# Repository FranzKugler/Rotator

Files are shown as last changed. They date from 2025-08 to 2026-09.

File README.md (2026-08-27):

# Rotator

ESP32-S3 firmware for an astronomical instrument rotator. The device drives a
stepper motor, measures the shaft angle, exposes an **ASCOM Alpaca Rotator** over
the network, and serves a local browser interface for movement, calibration and
network setup.

The firmware is an ESP-IDF project with Arduino-ESP32 included as a component.
It targets a **Seeed Studio XIAO ESP32-S3 with 16 MB flash**.

## Features

- ASCOM Alpaca Rotator API and Alpaca discovery
- Absolute, relative and mechanical-angle movement
- TMC2209 stepper driver and FastAccelStepper motion control
- AS5600 magnetic angle feedback
- Hall-sensor mechanical-zero search
- Fourier-based angle-sensor calibration and an extended Kalman filter
- Browser UI from a LittleFS partition, including live angle updates
- Wi-Fi station support plus USB RNDIS networking
- USB CDC logging, FTP access and OTA firmware updates
- QlockThreeW32-style GitHub update channels (stable/edge), version checks,
  verified one-click installation, scheduled automatic updates and local image upload

## Hardware

| Function | Device / GPIO |
|---|---|
| Controller | Seeed Studio XIAO ESP32-S3, 16 MB flash |
| Stepper driver UART RX / TX | GPIO 7 / GPIO 8 |
| Stepper enable | GPIO 1 |
| Step / direction | GPIO 3 / GPIO 4 |
| AS5600 I²C SDA / SCL | GPIO 5 / GPIO 6 |
| AS5600 direction | GPIO 43 |
| Mechanical-zero Hall sensor | GPIO 2, active low with pull-up |

The current motion model assumes a 400-full-step motor, 256 microsteps and a
10:1 reduction. Hardware constants and the pin assignment live in
[`main/RotatorHW.cpp`](main/RotatorHW.cpp).

> **Warning:** the firmware moves to mechanical zero during startup. Do not run
> newly built firmware on connected mechanics until the pinout, travel and motor
> current have been checked.

## Development environment

The supported build environment is the repository's Docker/Dev Container. It
pins ESP-IDF 5.4.1 and Claude Code and keeps the ESP-IDF, npm and Claude state in
named volumes. Only this repository is bind-mounted into the container; no
Docker socket or host home directory is exposed.

Prerequisites on the host:

- Docker Engine with Docker Compose
- Git

```sh
# Build and start the development container
scripts/dev-container.sh up

# Test/build Svelte, then build firmware, bootloader, partitions and LittleFS
scripts/dev-container.sh build

# Only test and build the Svelte interface into main/data
scripts/dev-container.sh web

# Open an ESP-IDF shell
scripts/dev-container.sh shell

# Start Claude Code in the project
scripts/dev-container.sh claude
```

The first image build downloads ESP-IDF and installs the pinned Claude Code
release. The first project build resolves npm and ESP-IDF managed components.
The browser UI is a Svelte 5/Vite application under `web/`; its production
output replaces `main/data/` before ESP-IDF creates `littlefs.bin`.

### Releases and versions

The fallback project version starts at **0.8.0**. A release tag such as
`v0.8.0` produces the bare version `0.8.0`; later commits become strings such as
`0.8.0-4-gabc123`, matching QlockThreeW32. Pushes to `main` replace the rolling
`edge` pre-release, while `v*` tags create stable releases. Each release contains
`Rotator.bin`, `littlefs.bin` and a checksummed `manifest.json`.

### Direct ESP-IDF commands

Inside `scripts/dev-container.sh shell`:

```sh
idf.py set-target esp32s3
idf.py build
idf.py size
idf.py menuconfig
idf.py fullclean
```

The project defaults are in [`sdkconfig.defaults`](sdkconfig.defaults), and the
16 MB flash layout is in [`partitions.csv`](partitions.csv). Build artifacts are
written to `build/`; the generated LittleFS image is part of the normal
`idf.py build` because `main/CMakeLists.txt` calls
`littlefs_create_partition_image()`.

## Flashing and monitoring

USB devices are deliberately **not** passed into the normal development
container. This keeps ordinary builds and Claude Code isolated from host
hardware. Once a device is attached, identify its stable
`/dev/serial/by-id/...` path and add only that device in a local Compose
override before using:

```sh
idf.py -p /dev/serial/by-id/<device> flash monitor
```

Do not solve serial access with `privileged: true` or a blanket `/dev` mount.

## Project layout

```text
main/                       application firmware and generated browser UI
  alpaca_server/            ASCOM Alpaca API and discovery implementation
  data/                     files packed into the LittleFS image
components/                 vendored Arduino and hardware-related components
web/                        Svelte 5 source for the embedded interface
tests/                      web API unit tests
partitions.csv              16 MB flash layout
sdkconfig.defaults          ESP32-S3 project defaults
.devcontainer/              pinned Docker/Dev Container definition
scripts/dev-container.sh    host-side environment helper
```

Configuration is stored as `/lfs/config.json`. Wi-Fi credentials are stored in
NVS. The default USB RNDIS address is `192.168.7.1/24`; its locally administered
MAC address and the angle-correction coefficients are defined in
[`main/Configuration.cpp`](main/Configuration.cpp) and can be changed through
the web API.

## Current project status

This repository currently has no automated test suite. The minimum acceptance
check for every change is therefore a clean `idf.py build` in the pinned
container, followed by targeted hardware testing when motion, calibration,
networking, USB or flash behaviour is affected.

## License

No project-wide license file is currently present. Vendored components retain
their respective upstream licenses.

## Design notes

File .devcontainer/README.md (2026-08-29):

# Rotator development container

This environment pins ESP-IDF 5.4.1 by immutable image digest and Claude Code
2.1.247. Run it through `scripts/dev-container.sh` from anywhere inside the
repository.

State is separated as follows:

- repository: bind-mounted at `/workspace`;
- compiler cache: named `idf-cache` volume;
- npm cache: named `npm-cache` volume;
- Claude Code account and sessions: named `claude-state` volume;
- SSH keys and known_hosts: named `ssh-state` volume, mounted at
  `/home/developer/.ssh`.

The service runs as a non-root user matching Franz's host UID/GID. It has all
Linux capabilities dropped, `no-new-privileges`, no Docker socket, no host-home
mount, no published ports and no hardware devices.

Authenticate Claude independently inside the container with
`scripts/dev-container.sh claude`. Credentials stay in the private named volume
and are neither baked into the image nor committed to Git.

USB flashing is intentionally separate. Add only a stable
`/dev/serial/by-id/...` device in a local Compose override after the target is
attached; never enable privileged mode or mount all of `/dev`.

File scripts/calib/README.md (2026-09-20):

# Rotator calibration campaign

A from-scratch calibration of the rotator's angle chain, built 2026-09-18.
Everything here drives real hardware over the network; nothing is simulated
except where a script says so.

    rotator   172.22.102.30      expert mode must be unlocked
    camera    172.22.102.226     RotatorCam, GET /capture

## The chain, and where each part is measured

    stepper --- AS5600 --- 10:1 reduction --- output shaft --- chessboard
                  |                                               |
            sensor sees this                             camera sees this

The AS5600 sits on the motor shaft, so it measures the motor and only
*infers* the output. That split decides the whole campaign: everything
upstream of the reduction can be calibrated from the sensor alone, and
everything downstream cannot be seen by it at all.

## Order of operations

| Step | Script | What it establishes |
|---|---|---|
| 1 | `sweep_fullstep.py` | raw sensor at each of the 400 full steps, forward and reverse. The firmware now does the same thing itself - `GET /api/calibration/angle/stream` - so this is the research version, not the only way |
| 2 | `fit_sensor.py` | Fourier correction, order chosen from the data; hysteresis and repeatability |
| 3 | `plot_sensor.py` | the calibration graphs |
| 4 | `upload_coefficients.py` | writes the fit to the device without moving its zero |
| 5 | `capture_frames.py --mode steps` | camera frames at exactly known positions |
| 6 | `fit_camera.py` | camera geometry (see the caveat below) |
| 7 | `gear_error.py` + `plot_gear.py` | what the sensor cannot see |
| 8 | `control_lab.py` | P / PI / PD / PID compared on the real machine |
| 8b | `log_tail.py` | drains the device's /log ring buffer, which wraps in ~30 s |
| 9 | `capture_frames.py --mode alpaca` + `measure_frames.py` | the end-to-end test run |
| 10 | `error_budget.py` | splits that run into loop / backlash / gear shape, cross-validated |
| 10b | `angle_service.py` | serves the output-shaft angle over HTTP, so the device can calibrate against it by itself |
| 11 | `plot_validation.py` | the test-run graph |

`rotator_io.py`, `board.py`, `camera_model.py`, `gear_model.py` and
`vizstyle.py` are the shared layers; none of them is a program.

`capture_frames.py --mode alpaca` takes two options that exist because of
what step 10 found: `--approach-deg` reaches every target from the same
side, which removes the gear backlash the firmware's loop cannot see, and
`--precompensate` shifts each target by a measured gear model so the shaft
lands where the target says rather than where the sensor says.

## Three things that will bite

**OpenCV's solver path crashes here.** This machine's CPU is a QEMU virtual
CPU with SSE4.2 and no AVX, and OpenCV's Levenberg-Marquardt code hits an
illegal instruction on it. `cv2.calibrateCamera`, `cv2.findHomography`,
`cv2.solvePnP` with `SOLVEPNP_ITERATIVE` and `cv2.solvePnPRefineLM` all die
with SIGILL - no exception, no traceback, just a dead process. The
closed-form routines are fine: `findChessboardCornersSB`, `solvePnP` with
`SOLVEPNP_IPPE`, `undistortPoints`, `projectPoints`, `Rodrigues`.
`camera_model.py` therefore carries its own DLT homography and its own
least-squares fits.

**The board's orientation is ambiguous by 180 degrees.** The 8x7 interior-
corner grid maps onto itself under a half turn, so both pairings fit
perfectly and no geometric test can separate them. `board.py` explains it;
`measure_frames.resolve_flips()` settles it against the rotator's own
reported position.

**Focal length is not observable on this rig.** The board plane sits within
0.1 degrees of perpendicular to the rotation axis, so rotating it produces
no new plane orientations and the focal length is free. A first fit ran away
to f = 8000 px while still reproducing corners to 0.29 px. This is not a
problem to solve - a board that stays in one fixed plane is the easy case,
and the homography-ratio estimator in `measure_frames.py` never needs a
focal length. `fit_camera.py` is kept for the diagnosis, not for production.

## Letting the device calibrate itself against the camera

The firmware can run the output-angle calibration on its own - a button in
the web UI, `GET /api/calibration/camera/stream` underneath - but it does no
image processing. It asks an HTTP address for a number. `angle_service.py`
is what answers, until RotatorCam serves angles itself:

    python3 scripts/calib/angle_service.py --camera 172.22.102.226 --port 8080

Then set the device's angle source (web UI, or POST
`/api/calibration/camera-source`) to `http://<that host>:8080/angle` and
press the button.

**It has to be reachable from the rotator, which the dev container is not.**
The container sits on a Docker bridge (172.23.0.0/16) that the rotator's
network does not route to, and `compose.yaml` publishes only the Vite port,
bound to localhost. Run the service on the host instead - it needs numpy and
opencv, the same throwaway venv as the rest of the analysis - or publish a
port from the container deliberately.

If the sign comes out inverted the device will refuse the result rather than
store it: a correction that big cannot be a gear error, and it says so.
Re-run the service with `--invert`.

## Environments

Acquisition is standard library only and runs under the container's own
python3. Analysis needs numpy, scipy, opencv and matplotlib in a throwaway
venv, per the note in `../requirements-camera-analysis.txt`:

    python3 -m venv /tmp/cv4
    /tmp/cv4/bin/pip install "opencv-python-headless==4.10.0.84" numpy scipy matplotlib

## Results as of 2026-09-18

Measured on the one unit, after the firmware switched to the AS5600's RAW
ANGLE register:

| | |
|---|---|
| sensor characteristic, uncorrected | 0.225 deg p-p |
| after the order-5 Fourier fit | 3.0 mdeg rms |
| useful harmonic orders | 1..5; order 6 and beyond are 0.02-0.03 counts, i.e. noise |
| forward repeatability | 1.3 mdeg |
| direction hysteresis (motor shaft) | 27.9 mdeg |
| camera repeatability | 2.3 mdeg (1.3 mdeg over 3 frames) |
| **output error the sensor cannot see** | **~37 mdeg rms, ~150 mdeg p-p** |
| direction split on randomly ordered targets | 64 mdeg p-p, 38.7 after the firmware's one-sided approach |
| lost motion on reversal | ~89 mdeg |
| position hysteresis no approach length removes | ~25-30 mdeg |
| firmware closed loop, sensor against Alpaca target | 3.9 mdeg rms |

The last two lines matter together: the firmware already positions the motor
shaft to better than 0.01 degrees, so every remaining error is downstream of
the reduction. Approaching every target from the same side removes the part of the split
that is backlash; `refineToTarget()` and `holdTask()` now do that on their
own, and `--approach-deg` does the same from the host side. What is left is
stiction, which no approach discipline touches.

The gear error is the accuracy floor of a calibration done without a camera.
It reproduced across two runs taken at different step spacings, agreeing to
0.8 degrees of phase on its dominant term, so it is a fixed property of the
machine and correctable - but only against an external reference.

The device stores orders up to KMAX = 5 as of v0.10.0, with the NVS blob
carrying its own KMAX and migrating a smaller one. Coefficients, mechanical
zero and full-step table share a generation number so a correction replaced
without re-measuring the other two is reported rather than silently applied -
`GET /api/calibration/status`, and `upload_coefficients.py --keep-zero` for
the one case where the caller has arranged for the zero to stay valid.

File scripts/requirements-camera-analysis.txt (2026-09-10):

# Only scripts/camera_angle_analyze.py needs these - deliberately NOT part of
# the ESP-IDF dev container's pinned Python env (see CLAUDE.md: don't install
# extra Python packages on the toolchain host). Use a throwaway venv:
#
#   python3 -m venv /tmp/camvenv
#   /tmp/camvenv/bin/pip install -r scripts/requirements-camera-analysis.txt
#   /tmp/camvenv/bin/python scripts/camera_angle_analyze.py --sweep-dir ...
numpy
opencv-python-headless

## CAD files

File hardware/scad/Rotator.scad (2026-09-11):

include <BOSL2/std.scad>
include <BOSL2/ball_bearings.scad>
include <BOSL2/screws.scad>

$fn=256;
extension_tube_outer_diameter = 44.5;
extension_tube_inner_diameter = 42;
bearing_outer_diameter = 72.4;
bearing_inner_diameter = 55.2;
bearing_height = 9;
no_of_clips = 3;
motor_distance = 75.8;  // calculated optimal distance of motor in x direction dependent on the used beltlength
cover_length = 50;      // length of motor cover - 20, so this is 70 long in fact
cover_width = 26;       // width of motor cover - 20, so this is 46 wide in fact
with_supports = true;
with_bearing_clips = false;


module esp_clip(){
    difference() {
        hull(){
            translate([0,-10.5,0])cylinder(d=4, h=2);
            translate([0, 10.5,0])cylinder(d=4, h=2);
        }
        translate([0,-10.5,-1])cylinder(d=2.5, h=4);
        translate([0, 10.5,-1])cylinder(d=2.5, h=4);
    }
}

module tmc_clip(){
    difference(){
        union(){
            hull(){
                translate([0,-9,0])cylinder(d=4, h=2);
                translate([0, 9,0])cylinder(d=4, h=2);
            }    
            hull(){
                translate([-2,-2,0])cylinder(d=4, h=2);
                translate([-2, 2,0])cylinder(d=4, h=2);
            }  
        }
        translate([0,-9,-1])cylinder(d=2.5, h=4);
        translate([0, 9,-1])cylinder(d=2.5, h=4);
    }
}

module sensor_clip(){
    difference(){
        cuboid([4,8,2], anchor=BOTTOM);
        translate([0,0,-1])cylinder(d=2.5, h=4);
    }
    translate([2,0,0])cuboid([2,8,6], anchor=BOTTOM+LEFT);
}

module hall_clip() {
    difference() {
        diff() prismoid([7,10-0.8],[7,5.65-0.8], height=2.6, anchor=BOTTOM+LEFT) edge_profile(TOP+RIGHT, excess=2)mask2d_roundover(h=1); 
        translate([1.6,0,-1])cuboid([3.4,4.5,3], anchor=BOTTOM+LEFT);
        translate([-1,0,-1])cuboid([4,3.6,2], anchor=BOTTOM+LEFT);
    }   
}

module distance_ring(h=5) {
    difference(){
        union(){
            // tube with outer diameter and thread with inner diameter
            cylinder(d=extension_tube_outer_diameter, h=h);
            translate([0,0,h]) threaded_rod(d=extension_tube_inner_diameter, pitch=0.75, h=6);
        }
        // minus the bore of the tube itself
        translate([0,0,-1])cylinder(d=extension_tube_inner_diameter-2, h=h+4);
    }
}
  
module rotating_ring(){
    difference(){
        // pulley with dome
        union(){
            import("Imports/BigPulley.obj");
            translate([0,0,5.2+2.2])cyl(h=5, d1=94, d2=94-6, rounding1=-2, rounding2=2);
           
        }
        // hole for the extension tube
        translate([0,0,-1])cyl(d=extension_tube_outer_diameter+0.2, h=10.9, chamfer2=-0.6, anchor=BOTTOM);
        // carve out inner part
        translate([0,0,8.6/2])cyl(h=8.6, d=bearing_outer_diameter+13, rounding1=-1, rounding2=1);
        // hole for the index magnet
        translate([-(bearing_outer_diameter+13)/2-3.6,0,4.1])yrot(90)cyl(d=6.3, h=4, chamfer1=-0.4, anchor=BOTTOM);

        
    }
    // inner cylinder connected to inner ring of the bearing
    difference(){
        // cylinder
        translate([0,0,-1])cylinder(d=bearing_inner_diameter, h=9.7);
        // minus the hole for the extension tube
        translate([0,0,-1])cylinder(d=extension_tube_outer_diameter+0.2, h=12); 
        // minus the 45deg phase
        //translate([0,0,0])cylinder(h=(bearing_inner_diameter-extension_tube_outer_diameter)/2, d1=bearing_inner_diameter, d2=extension_tube_outer_diameter);
        translate([0,0,-1.4])cyl(d=bearing_inner_diameter-2, h=6.5, rounding2=(bearing_inner_diameter-extension_tube_outer_diameter)/2, anchor=BOTTOM);
        // trim to height
        translate([0,0,-1])cylinder(h=1, d=55);
        // cutouts for bearing clips
        if(with_bearing_clips)  
            for (w=[0:360/no_of_clips:360-360/no_of_clips])rotate([0,0,w])translate([-bearing_inner_diameter/2-2,-3.5, -2]) cube([4,7,11]);
    }
    // bearing seat
    difference(){
        translate([0,0,7.6+0.2])cylinder(d=bearing_inner_diameter+5, h=1.2);
        translate([0,0,6])cylinder(d=bearing_inner_diameter-5, h=5);
    }
    // tube stop ring
    difference() {
        union(){
            #translate([0,0,5.0])cylinder(d1=extension_tube_outer_diameter+2,d2=extension_tube_outer_diameter-3, h=1.4);
            translate([0,0,5.0+4.7/2])threaded_rod(d=extension_tube_inner_diameter+0.2, pitch=0.75, h=4.7);
            translate([0,0,9.5])cylinder(d=extension_tube_inner_diameter-1, h=0.2);
            }
        translate([0,0,2.0])cylinder(d=extension_tube_inner_diameter-2.4, h=10);
    }

    // bearing clips
    if(with_bearing_clips){
        for (w=[0:360/no_of_clips:360-360/no_of_clips])rotate([0,0,180 + w + 180 * 5 / bearing_outer_diameter / PI])
        difference(){
            translate([0,0,-1.6])cyl(d=bearing_inner_diameter, h=9.4, rounding1=-1, anchor=BOTTOM);
            translate([0,0,-2])pie_slice(h = 12, d=bearing_inner_diameter+3, ang = 360-360 * 5 / bearing_outer_diameter / PI, anchor=BOTTOM);
            translate([0,0,-3])cyl(h=10.5, d1=bearing_inner_diameter-2, d2=bearing_inner_diameter-2, rounding2=1, anchor=BOTTOM);
            translate([0,0,-3])cylinder(h=13, d=bearing_inner_diameter-6);
        }
    }
    // eventually print support ring
    if (with_supports) translate([0,0,9.9-1.4])difference(){
        cyl(d=105, h=1.4, anchor=BOTTOM);
        translate([0,0,-0.1])cylinder(d=91, h=2);
    } 
    if (false) translate([0,0,9.9-1.6])difference(){
        cyl(d=extension_tube_inner_diameter, h=1.6, anchor=BOTTOM);
        translate([0,0,-0.1])cylinder(d=extension_tube_inner_diameter-8, h=2);
        }
}  

module small_pulley(){
    difference(){
        import("Imports/SmallPulley.obj");
        translate([0,0,-1])cyl(d=5.3, h=9.2, chamfer2=-1, anchor=BOTTOM, $fn=64);
        // magnet
        translate([0,0,-1])cylinder(d=6.3, h=3.1,   $fn=64);
        // room for sensor
        translate([0,0,-1])cylinder(d=8,   h=1.8, $fn=64);
    }
    // add index D-Shape
    rotate([0,0,-90])translate([2.1,-2.5,2.5]) cube([0.7,5,4]);  
}

module mounting_post(){
    difference(){
        translate([0,0,6.2])cyl(d=8, h=12.4, rounding1=-2); 
        translate([0,0,3.5+12.4-7])cyl(d=4, h=7, chamfer2=-0.4);
        translate([0,0,2])cylinder(d=3.3, h=12);
    }   
}

// bottom housing
module bottom (){
    difference(){
        // bottom plate
        union(){
            hull(){
                translate([0,0,-1])cyl(d=140, h=2, chamfer1=1);
                translate([-90,-60,-1])cyl(d=20, h=2, chamfer1=1);
                translate([-90, 60,-1])cyl(d=20, h=2, chamfer1=1);
                
            }
            // tube foot
            cylinder(h=5, d1=49, d2=45);
            // tube main cylinder where the thread gets cut out
            translate([0,0,2])cyl(h=4, d=47, rounding2=1, anchor=BOTTOM);
        }
        // hole for extension tube
        translate([0,0,-2])cyl(d=extension_tube_outer_diameter, h=6, chamfer1=-1, anchor=BOTTOM);
        // thread for extension tube
        translate([0,0,3])threaded_rod(d=extension_tube_inner_diameter+0.6, pitch=0.75, h=6);
        // pocket for rotation sensor
        translate([-motor_distance,0,-1.4])cuboid([23.6,23.8,2], rounding=3.2, edges=[FWD+RIGHT,FWD+LEFT,BACK+RIGHT,BACK+LEFT], anchor=BOTTOM); //rounding=3.5
        // cutout for hall sensor
        translate([-bearing_outer_diameter/2-2,0,-1])cuboid([20,5.65,2], chamfer=-1, edges=[BOTTOM+FRONT,BOTTOM+BACK], anchor=BOTTOM+RIGHT);
        translate([-bearing_outer_diameter/2-6,0,-1])rotate([0,-90,0])prismoid([11,10],[11,4], height=4, anchor=TOP+LEFT);
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

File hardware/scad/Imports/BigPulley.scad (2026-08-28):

// Parametric Pulley with multiple belt profiles
// by droftarts January 2012
// updated and changed by Oscar January 2018 (https://www.thingiverse.com/0scar/about)

// Based on pulleys by:
// http://www.thingiverse.com/thing:11256 by me!
// https://github.com/prusajr/PrusaMendel by Josef Prusa
// http://www.thingiverse.com/thing:3104 by GilesBathgate
// http://www.thingiverse.com/thing:2079 by nophead

// dxf tooth data from http://oem.cadregister.com/asp/PPOW_Entry.asp?company=915217&elementID=07807803/METRIC/URETH/WV0025/F
// pulley diameter checked and modelled from data at http://www.sdp-si.com/D265/HTML/D265T016.html

/**
 * @name Pulley
 * @category Printed
 * @using 1 x m3 nut, normal or nyloc
 * @using 1 x m3x10 set screw or 1 x m3x8 grub screw
 */

// ------------------------
// Idler profile parameters
// ------------------------
number_of_teeth = 160; // [10:100]
profile = 12; // [1:MXL, 2:40DP, 3:XL, 4:H, 5:T2.5, 6:T5, 7:T10, 8:AT5, 9:HTD_3mm, 10:HTD_5mm, 11:HTD_8mm, 12:GT2_2mm, 13:GT2_3mm, 14:GT2_5mm]
motor_shaft_diameter = 8.2; // (in mm)
toothed_part_length = 6.2; // [3:30] (in mm)
base_height = 0; // [0:30] (in mm, 6 is typical)
base_diameter = 20;   // [10:50] (in mm)

// ---------------------------
// Idler & retainer parameters
// ---------------------------
belt_retainer = 1; // [0:No, 1:Yes]
retainer_height_p = 1.0; // [0.5:Tiny (0.5mm), 1:Small (1mm), 1.5:Normal (1.5mm), 2:Big (2mm), 3:Bigger (3mm), 4:Hudge (5mm)]
belt_idler = 1; // [0:No, 1:Yes]
// Height of idler flange over pulley. Set to same as base height if you want an idler but no pulley.
idler_height_p = 1.0; // [0.5:Tiny (0.5mm), 1:Small (1mm), 1.5:Normal (1.5mm), 2:Big (2mm), 3:Bigger (3mm), 4:Hudge (5mm)]

// ---------------
// Shaft fastening
// ---------------
screws_disposition = 3; // [0:None, 1:1 screw, 2:2 screws at 90deg, 3:3 screws at 120deg, 4:4 screws at 90deg]
nut_shape = 1; // [1:Hexagonal, 0:Square]
screw_profile = 4; // [0:M1, 1:M1.6, 2:M2, 3:M2.5, 4:M3, 5:M4, 6:M5, 7:M6]

// Distance between inner face of nut and shaft - can be negative - (in mm).
nut_shaft_distance = 1.2;

// Bolt head shape (0 is inactive) subtracts a bolt head sized hexagon for hexagon bolts
idler_bolt_option = 0; // [0:none, 1:M3, 2:M4, 3:M5, 4:M6, 5:M8, 6:M10, 7:M12, 8:custom] for custom: make changes below!

// Optional metal flange attachment (0 is inactive)
flange_option = 1;
flange_screw_profile = 5; // [0:M1, 1:M1.6, 2:M2, 3:M2.5, 4:M3, 5:M4, 6:M5, 7:M6]
flange_screws_disposition = 4; // [0:None, 1:1 screw, 2:2 screws at 180deg, 3:3 screws at 120deg, 4:4 screws at 90deg]
flange_screwoffset_radius = 26/2;
flange_diam = 32; // Set to zero to disable the flange to be sunk in the idler
flange_thickness = 3; // Set to zero to disable the flange to be sunk in the idler
flange_use_tap = 1; // Diameter is smaller when used for tapping, 0 to larger hole for easy fit


// --------------------------------------------------
// ADVANCED parameters for scaling tooth for good fit
// --------------------------------------------------
// To improve fit of belt to pulley, set the following constant.
// Decrease or increase by 0.1mm at a time. We are modelling the
// *BELT* tooth here, not the tooth on the pulley. Increasing the
// number will *decrease* the pulley tooth size. Increasing the
// tooth width will also scale proportionately the tooth depth,
// to maintain the shape of the tooth, and increase how far into
// the pulley the tooth is indented. Can be negative too!
additional_tooth_width = 0.2; //mm
// If you need more tooth depth than this provides, adjust the
// following constant. However, this will cause the shape of the
// tooth to change.
additional_tooth_depth = 0; //mm

// ------------------------------------
// Calculated parameters (do not alter)
// ------------------------------------
idler_height = (belt_idler==0 ? 0 : idler_height_p);
retainer_height = (belt_retainer==0 ? 0 : retainer_height_p);
//echo (str("Idler height\t= ",idler_height," mm"));
//echo (str("Retainer height\t= ",retainer_height," mm"));
no_of_nuts = screws_disposition;
nut_angle = no_of_nuts != 3 ? 90 : 120;
motor_shaft = motor_shaft_diameter + 0.2;
screw_diameters = [1, 1.6, 2, 2.5, 3, 4, 5, 6];
nut_widths = [2.5, 3.2, 4, 5, 5.5, 7, 8, 10];
nut_depths = [1, 1.3, 1.6, 2, 2.4, 3.2, 4.7, 5.2];
// bolthead size circ.[ none,    M3,    M4,   M5,    M6,    M8,   M10,   M12, custom]
bolt_head_diameters = [0.000, 6.010, 7.660, 8.79, 11.05, 14.38, 17.77, 20.03,  15.8]; // circle diameter, not width across flats!
bolt_head_heights =   [0.000, 2.125, 2.925, 3.65,  4.15,  5.45,  6.58,  7.68,   5.5];
screw_diameter = screw_diameters[screw_profile] + 0.2;
nut_width = nut_widths[screw_profile] + 0.2;
nut_depth = nut_depths[screw_profile] + 0.3;
bolt_head_diam = bolt_head_diameters[idler_bolt_option] + 0.2; // + 0.1-2 for tight fit
bolt_head_height = bolt_head_heights[idler_bolt_option] + 0.2;
screw_hole_sf = flange_use_tap == 1 ? 0.9 : 1.1; // 0.9 is the recommended value for taps of fine thread, 0.85 for coarse threads
flange_screw_diameter = screw_diameters[flange_screw_profile] * screw_hole_sf; 
flange_no_of_screws = flange_screws_disposition;
flange_screw_angle = flange_no_of_screws != 3 ? (flange_no_of_screws == 2 ? 180 : 90) : 120;

// --------------------
// Calculated constants
// --------------------
nut_elevation = base_height/2;
metric_nut_width_across_points = 2*((nut_width/2)/cos(30)); // This is needed for the nut trap
// The following set the pulley diameter for a given number of teeth
MXL_pulley_dia = tooth_spacing (2.032,0.254);
40DP_pulley_dia = tooth_spacing (2.07264,0.1778);
XL_pulley_dia = tooth_spacing (5.08,0.254);
H_pulley_dia = tooth_spacing (9.525,0.381);
T2_5_pulley_dia = tooth_spaceing_curvefit (0.7467,0.796,1.026);
T5_pulley_dia = tooth_spaceing_curvefit (0.6523,1.591,1.064);
T10_pulley_dia = tooth_spacing (10,0.93);
AT5_pulley_dia = tooth_spaceing_curvefit (0.6523,1.591,1.064);
HTD_3mm_pulley_dia = tooth_spacing (3,0.381);
HTD_5mm_pulley_dia = tooth_spacing (5,0.5715);
HTD_8mm_pulley_dia = tooth_spacing (8,0.6858);
GT2_2mm_pulley_dia = tooth_spacing (2,0.254);
GT2_3mm_pulley_dia = tooth_spacing (3,0.381);
GT2_5mm_pulley_dia = tooth_spacing (5,0.5715);
// The following calls the pulley creation part, and passes the pulley diameter and tooth width to that module
if ( profile == 1 ) {pulley("MXL" , MXL_pulley_dia , 0.508 , 1.321 ); }
if ( profile == 2 ) {pulley("40 D.P." , 40DP_pulley_dia , 0.457 , 1.226 ); }
if ( profile == 3 ) {pulley("XL" , XL_pulley_dia , 1.27, 3.051 ); }
if ( profile == 4 ) {pulley("H" , H_pulley_dia ,1.905 , 5.359 ); }
if ( profile == 5 ) {pulley("T2.5" , T2_5_pulley_dia , 0.7 , 1.678 ); }
if ( profile == 6 ) {pulley("T5" , T5_pulley_dia , 1.19 , 3.264 ); }
if ( profile == 7 ) {pulley("T10" , T10_pulley_dia , 2.5 , 6.13 ); }
if ( profile == 8 ) {pulley("AT5" , AT5_pulley_dia , 1.19 , 4.268 ); }
if ( profile == 9 ) {pulley("HTD 3mm" , HTD_3mm_pulley_dia , 1.289 , 2.27 ); }
if ( profile == 10 ){pulley("HTD 5mm" , HTD_5mm_pulley_dia , 2.199 , 3.781 ); }
if ( profile == 11 ){pulley("HTD 8mm" , HTD_8mm_pulley_dia , 3.607 , 6.603 ); }
if ( profile == 12 ){pulley("GT2 2mm" , GT2_2mm_pulley_dia , 0.764 , 1.494 ); }
if ( profile == 13 ){pulley("GT2 3mm" , GT2_3mm_pulley_dia , 1.169 , 2.31 ); }
if ( profile == 14 ){pulley("GT2 5mm" , GT2_5mm_pulley_dia , 1.969 , 3.952 ); }

// ---------
// Functions
// ---------
function tooth_spaceing_curvefit (b,c,d)
  = ((c * pow(number_of_teeth,d)) / (b + pow(number_of_teeth,d))) * number_of_teeth ;

function tooth_spacing(tooth_pitch,pitch_line_offset)
  = (2*((number_of_teeth*tooth_pitch)/(3.14159265*2)-pitch_line_offset)) ;

// ================================================================================
// Main Module
// ================================================================================
module pulley( belt_type , pulley_OD , tooth_depth , tooth_width ){
  echo (str("Belt type = ",belt_type,"; Number of teeth = ",number_of_teeth,"; Pulley Outside Diameter = ",pulley_OD,"mm "));
  tooth_distance_from_centre = sqrt( pow(pulley_OD/2,2) - pow((tooth_width+additional_tooth_width)/2,2));
  tooth_width_scale = (tooth_width + additional_tooth_width ) / tooth_width;
  tooth_depth_scale = ((tooth_depth + additional_tooth_depth ) / tooth_depth) ;

  difference(){   
    translate([0,0,idler_height]){
      union(){
        //base
        if (( base_height < 2 ) && (no_of_nuts > 0)){ 
          if (base_height != 0){
            echo ("CAN'T DRAW PULLEY BASE, HEIGHT LESS THAN 2!!!"); 
          }
        } else {
          translate([0,0,-idler_height]){
            cylinder(d=base_diameter, h=base_height, $fn=base_diameter*20, center=false);
          }
        }
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

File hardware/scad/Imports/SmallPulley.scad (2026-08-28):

// Parametric Pulley with multiple belt profiles
// by droftarts January 2012
// updated and changed by Oscar January 2018 (https://www.thingiverse.com/0scar/about)

// Based on pulleys by:
// http://www.thingiverse.com/thing:11256 by me!
// https://github.com/prusajr/PrusaMendel by Josef Prusa
// http://www.thingiverse.com/thing:3104 by GilesBathgate
// http://www.thingiverse.com/thing:2079 by nophead

// dxf tooth data from http://oem.cadregister.com/asp/PPOW_Entry.asp?company=915217&elementID=07807803/METRIC/URETH/WV0025/F
// pulley diameter checked and modelled from data at http://www.sdp-si.com/D265/HTML/D265T016.html

/**
 * @name Pulley
 * @category Printed
 * @using 1 x m3 nut, normal or nyloc
 * @using 1 x m3x10 set screw or 1 x m3x8 grub screw
 */

// ------------------------
// Idler profile parameters
// ------------------------
number_of_teeth = 160; // [10:100]
profile = 12; // [1:MXL, 2:40DP, 3:XL, 4:H, 5:T2.5, 6:T5, 7:T10, 8:AT5, 9:HTD_3mm, 10:HTD_5mm, 11:HTD_8mm, 12:GT2_2mm, 13:GT2_3mm, 14:GT2_5mm]
motor_shaft_diameter = 8.2; // (in mm)
toothed_part_length = 6.2; // [3:30] (in mm)
base_height = 0; // [0:30] (in mm, 6 is typical)
base_diameter = 20;   // [10:50] (in mm)

// ---------------------------
// Idler & retainer parameters
// ---------------------------
belt_retainer = 1; // [0:No, 1:Yes]
retainer_height_p = 1.0; // [0.5:Tiny (0.5mm), 1:Small (1mm), 1.5:Normal (1.5mm), 2:Big (2mm), 3:Bigger (3mm), 4:Hudge (5mm)]
belt_idler = 1; // [0:No, 1:Yes]
// Height of idler flange over pulley. Set to same as base height if you want an idler but no pulley.
idler_height_p = 1.0; // [0.5:Tiny (0.5mm), 1:Small (1mm), 1.5:Normal (1.5mm), 2:Big (2mm), 3:Bigger (3mm), 4:Hudge (5mm)]

// ---------------
// Shaft fastening
// ---------------
screws_disposition = 3; // [0:None, 1:1 screw, 2:2 screws at 90deg, 3:3 screws at 120deg, 4:4 screws at 90deg]
nut_shape = 1; // [1:Hexagonal, 0:Square]
screw_profile = 4; // [0:M1, 1:M1.6, 2:M2, 3:M2.5, 4:M3, 5:M4, 6:M5, 7:M6]

// Distance between inner face of nut and shaft - can be negative - (in mm).
nut_shaft_distance = 1.2;

// Bolt head shape (0 is inactive) subtracts a bolt head sized hexagon for hexagon bolts
idler_bolt_option = 0; // [0:none, 1:M3, 2:M4, 3:M5, 4:M6, 5:M8, 6:M10, 7:M12, 8:custom] for custom: make changes below!

// Optional metal flange attachment (0 is inactive)
flange_option = 1;
flange_screw_profile = 5; // [0:M1, 1:M1.6, 2:M2, 3:M2.5, 4:M3, 5:M4, 6:M5, 7:M6]
flange_screws_disposition = 4; // [0:None, 1:1 screw, 2:2 screws at 180deg, 3:3 screws at 120deg, 4:4 screws at 90deg]
flange_screwoffset_radius = 26/2;
flange_diam = 32; // Set to zero to disable the flange to be sunk in the idler
flange_thickness = 3; // Set to zero to disable the flange to be sunk in the idler
flange_use_tap = 1; // Diameter is smaller when used for tapping, 0 to larger hole for easy fit


// --------------------------------------------------
// ADVANCED parameters for scaling tooth for good fit
// --------------------------------------------------
// To improve fit of belt to pulley, set the following constant.
// Decrease or increase by 0.1mm at a time. We are modelling the
// *BELT* tooth here, not the tooth on the pulley. Increasing the
// number will *decrease* the pulley tooth size. Increasing the
// tooth width will also scale proportionately the tooth depth,
// to maintain the shape of the tooth, and increase how far into
// the pulley the tooth is indented. Can be negative too!
additional_tooth_width = 0.2; //mm
// If you need more tooth depth than this provides, adjust the
// following constant. However, this will cause the shape of the
// tooth to change.
additional_tooth_depth = 0; //mm

// ------------------------------------
// Calculated parameters (do not alter)
// ------------------------------------
idler_height = (belt_idler==0 ? 0 : idler_height_p);
retainer_height = (belt_retainer==0 ? 0 : retainer_height_p);
//echo (str("Idler height\t= ",idler_height," mm"));
//echo (str("Retainer height\t= ",retainer_height," mm"));
no_of_nuts = screws_disposition;
nut_angle = no_of_nuts != 3 ? 90 : 120;
motor_shaft = motor_shaft_diameter + 0.2;
screw_diameters = [1, 1.6, 2, 2.5, 3, 4, 5, 6];
nut_widths = [2.5, 3.2, 4, 5, 5.5, 7, 8, 10];
nut_depths = [1, 1.3, 1.6, 2, 2.4, 3.2, 4.7, 5.2];
// bolthead size circ.[ none,    M3,    M4,   M5,    M6,    M8,   M10,   M12, custom]
bolt_head_diameters = [0.000, 6.010, 7.660, 8.79, 11.05, 14.38, 17.77, 20.03,  15.8]; // circle diameter, not width across flats!
bolt_head_heights =   [0.000, 2.125, 2.925, 3.65,  4.15,  5.45,  6.58,  7.68,   5.5];
screw_diameter = screw_diameters[screw_profile] + 0.2;
nut_width = nut_widths[screw_profile] + 0.2;
nut_depth = nut_depths[screw_profile] + 0.3;
bolt_head_diam = bolt_head_diameters[idler_bolt_option] + 0.2; // + 0.1-2 for tight fit
bolt_head_height = bolt_head_heights[idler_bolt_option] + 0.2;
screw_hole_sf = flange_use_tap == 1 ? 0.9 : 1.1; // 0.9 is the recommended value for taps of fine thread, 0.85 for coarse threads
flange_screw_diameter = screw_diameters[flange_screw_profile] * screw_hole_sf; 
flange_no_of_screws = flange_screws_disposition;
flange_screw_angle = flange_no_of_screws != 3 ? (flange_no_of_screws == 2 ? 180 : 90) : 120;

// --------------------
// Calculated constants
// --------------------
nut_elevation = base_height/2;
metric_nut_width_across_points = 2*((nut_width/2)/cos(30)); // This is needed for the nut trap
// The following set the pulley diameter for a given number of teeth
MXL_pulley_dia = tooth_spacing (2.032,0.254);
40DP_pulley_dia = tooth_spacing (2.07264,0.1778);
XL_pulley_dia = tooth_spacing (5.08,0.254);
H_pulley_dia = tooth_spacing (9.525,0.381);
T2_5_pulley_dia = tooth_spaceing_curvefit (0.7467,0.796,1.026);
T5_pulley_dia = tooth_spaceing_curvefit (0.6523,1.591,1.064);
T10_pulley_dia = tooth_spacing (10,0.93);
AT5_pulley_dia = tooth_spaceing_curvefit (0.6523,1.591,1.064);
HTD_3mm_pulley_dia = tooth_spacing (3,0.381);
HTD_5mm_pulley_dia = tooth_spacing (5,0.5715);
HTD_8mm_pulley_dia = tooth_spacing (8,0.6858);
GT2_2mm_pulley_dia = tooth_spacing (2,0.254);
GT2_3mm_pulley_dia = tooth_spacing (3,0.381);
GT2_5mm_pulley_dia = tooth_spacing (5,0.5715);
// The following calls the pulley creation part, and passes the pulley diameter and tooth width to that module
if ( profile == 1 ) {pulley("MXL" , MXL_pulley_dia , 0.508 , 1.321 ); }
if ( profile == 2 ) {pulley("40 D.P." , 40DP_pulley_dia , 0.457 , 1.226 ); }
if ( profile == 3 ) {pulley("XL" , XL_pulley_dia , 1.27, 3.051 ); }
if ( profile == 4 ) {pulley("H" , H_pulley_dia ,1.905 , 5.359 ); }
if ( profile == 5 ) {pulley("T2.5" , T2_5_pulley_dia , 0.7 , 1.678 ); }
if ( profile == 6 ) {pulley("T5" , T5_pulley_dia , 1.19 , 3.264 ); }
if ( profile == 7 ) {pulley("T10" , T10_pulley_dia , 2.5 , 6.13 ); }
if ( profile == 8 ) {pulley("AT5" , AT5_pulley_dia , 1.19 , 4.268 ); }
if ( profile == 9 ) {pulley("HTD 3mm" , HTD_3mm_pulley_dia , 1.289 , 2.27 ); }
if ( profile == 10 ){pulley("HTD 5mm" , HTD_5mm_pulley_dia , 2.199 , 3.781 ); }
if ( profile == 11 ){pulley("HTD 8mm" , HTD_8mm_pulley_dia , 3.607 , 6.603 ); }
if ( profile == 12 ){pulley("GT2 2mm" , GT2_2mm_pulley_dia , 0.764 , 1.494 ); }
if ( profile == 13 ){pulley("GT2 3mm" , GT2_3mm_pulley_dia , 1.169 , 2.31 ); }
if ( profile == 14 ){pulley("GT2 5mm" , GT2_5mm_pulley_dia , 1.969 , 3.952 ); }

// ---------
// Functions
// ---------
function tooth_spaceing_curvefit (b,c,d)
  = ((c * pow(number_of_teeth,d)) / (b + pow(number_of_teeth,d))) * number_of_teeth ;
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

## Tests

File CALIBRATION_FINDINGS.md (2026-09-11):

# Angle calibration findings

Working notes from a deep pass on the rotator's angle accuracy: the TMC2209
current bug, why the AS5600's own harmonic self-calibration is structurally
biased, the RotatorCam independent camera reference, and the closed-loop PI
controller that ended up mattering more than any of the sensor modeling.

All angles are **output-shaft degrees** unless stated otherwise (AS5600
raw/corrected values live in "counts", 4096/rev; motor-shaft degrees are
counts × 360/4096; output-shaft = motor-shaft / 10, the fixed gear
reduction).

## TMC2209 current fix

`RotatorHW::begin()` was overriding `setRMSCurrent()`'s computed run current
with the driver's absolute maximum (~980 mA) and leaving the hold current at
the small `setRMSCurrent()`-derived value - a ~16:1 run:hold mismatch, and
far beyond what the 17 ohm/phase coil can physically draw at 5V (~290 mA
ceiling), so StealthChop's current regulator saturated for most of each
microstep waveform. Fixed by removing the override and running at 280 mA
(safely under the ~290 mA ceiling). Live-verified via motor-sweep: not a
clean unambiguous win at every measured position, but net positive and the
only physically correct setting.

## AS5600 self-referential correction bias

`calibrateAngleSensorStep()`/`fit_fourier()` fit a harmonic error model with
phase `theta` taken from the sensor's own raw reading, because
`correctSensorReading()` never has anything else available at runtime. This
is a real, previously-documented, deliberately-accepted tradeoff (an
ideal-phase-basis version was tried once and made things worse - see
`RotatorHW.cpp`'s history) - but it comes at a cost that got a lot clearer
this pass:

- On a full-revolution sweep, a 4th-order self-referential fit was
  **reproducibly worse** than simply subtracting the mean (C0-only): 0.107 deg
  vs 0.065 deg RMS (output-shaft), confirmed at two averaging depths.
- At full-step resolution (400 points/revolution), the effect is dramatic:
  a 6th-order self-referential fit turned a 0.64 deg RMS C0-only residual
  into 2.3-6.3 deg (`calibration_lab.py fullstep-accuracy`). Not usable.
- The bias only goes away with an **independent** reference - i.e. not
  derived from the same raw reading being corrected. That's what the camera
  rig is for.

## RotatorCam: an independent, output-shaft-referenced reference

New side project (`../RotatorCam`, XIAO ESP32S3 Sense + OV2640): photographs
a printed checkerboard mounted on the rotation axis. Unlike the AS5600 (motor
shaft, upstream of the 10:1 reduction), the camera watches the true output
shaft directly. `scripts/camera_angle_sweep.py` drives a sweep and
photographs each point; `scripts/camera_angle_analyze.py` tracks rotation
frame-to-frame via sub-pixel checkerboard corner detection + a Procrustes
(rotation-only) fit, resolving the classic "which end is which" checkerboard
ambiguity by picking whichever candidate gives the smaller frame-to-frame
rotation (valid as long as steps stay well under ~90 deg).

**Camera repositioning mattered more than any correction did:** raising the
camera for better focus dropped the raw residual from 0.198 deg to 0.058 deg
RMS before any calibration. A "closure check" (comparing the same physical
angle visited a full revolution apart) went from 0.524 deg to 0.071 deg,
confirming most of the original error was focus/tracking noise, not real
mechanical slip.

### Eccentricity calibration (target mounting error)

The target can't be glued perfectly centered on the axis - Franz's proposal:
probe 10 points exactly 400 full steps apart (= exactly 1/10 output
revolution, same motor phase every time, verified via `align_fullstep()`),
fit a low-order (1st+2nd harmonic) model to those 10 camera residuals, and
subtract it from the whole sweep. Two independent runs (an 11-frame probe
and the full 361-frame sweep) agreed almost exactly on amplitude and phase -
strong validation. Result: camera RMS 0.058 -> 0.019 deg, finally below the
AS5600's own 0.064 deg.

### Refitting the AS5600 against the camera

With eccentricity removed, refitting the AS5600's harmonic model using the
camera as phase reference (instead of the sensor's own raw reading) at
**order 1 only** gave 0.047 deg RMS - beating the existing 0.064 deg bias-only
correction for the first time in this project, self- or externally-referenced.
Higher orders (2-6) got worse again - camera measurement noise dominates the
extra coefficients past order 1.

### Fitting method matters: least-squares vs. the correlation-sum formula

`fit_fourier_against_reference()`'s original implementation computed each
harmonic amplitude via the plain DFT-style correlation sum (`2/n * sum(
residual * cos/sin(k*theta))`) - exactly right when theta is sampled
uniformly over 0-360 deg (true for `calibration_lab.py`'s self-referential
`fit_fourier()`, whose theta is the sensor's own evenly-stepped raw
reading), but only approximately right when theta comes from the camera's
independent measurement, which has its own real nonlinearity/noise and so
is close to but not exactly evenly spaced. Live consequence
(2026-09-11, full-revolution sweep): the sum formula left 0.20-0.26 deg of
residual at orders 1-2 - the very orders it was supposed to already
remove. Switching to a proper linear least-squares solve
(`numpy.linalg.lstsq`) drove that to exactly 0 by construction and cut the
overall order<=4 residual roughly 5x (0.27 deg -> 0.055 deg motor-shaft
degrees on that sweep). Note from later in this file: this fit-quality
improvement alone did **not** reliably improve the real closed-loop
(Alpaca+camera) verification number - see "Full-step lookup table" below
for what turned out to matter more.

## Full-step accuracy (`calibration_lab.py fullstep-accuracy`)

400 points, one per full step, repeated over 2 motor revolutions:
- C0-only residual: 0.64 deg RMS, 1.41 deg peak (motor-shaft), dominated by
  the same known low orders (1,2,4). (Re-measured 2026-09-11 against the
  camera-refit model then in effect: order-6 residual RMS=1.30 deg,
  peak=3.56 deg - a different absolute number because the smooth model
  itself had changed by then, not a contradiction. The property that
  matters, rev-to-rev repeatability, was confirmed again below.)
- **Extremely repeatable** rev-to-rev: correlation +0.998, diff RMS 0.039 deg -
  a real, deterministic function of full-step position, not noise.
  (2026-09-11 re-check: correlation +1.000, diff RMS 0.049 deg - same
  conclusion.)
- One genuine, fully reproducible readout glitch found: `raw=4095.000`
  exactly, both revolutions, at the exact full step where the AS5600's raw
  register should wrap 4095->0 - looks like a torn read straddling the
  rollover, not a physical position error. `scripts/fullstep_table.py`
  despikes it before building anything from the data.
- Small (~0.02 deg motor-shaft) but real content near order ~100 - plausibly
  the motor's own rotor-tooth cogging (0.9 deg/step implies ~100 rotor teeth).

### Full-step lookup table: implemented and verified (2026-09-11)

The 400-entry lookup table sketched above is now real: `RotatorHW::
setFullStepTable()`/`getFullStepTable()`, applied in `correctSensorReading()`
as a zero-mean residual layered on top of C0/A[]/B[] (indexed by which full
step the already-smooth-corrected reading estimates it is nearest, linearly
interpolated), persisted in NVS (`"anglecal"/"fullsteptable"`), uploaded via
the expert-gated `/api/calibration/fullstep-table` endpoint. Built this time
from a **camera-referenced** capture (`scripts/camera_fullstep_sweep.py`,
2 motor revolutions, one photo per full step) instead of the self-referential
`fullstep-accuracy` data the original design sketch assumed -
`scripts/camera_fullstep_table.py` bins the smooth-corrected-vs-camera
residual per full step, despikes, mean-subtracts; `scripts/
upload_fullstep_table.py` pushes it.

Two real bugs found and fixed while building this, both worth knowing about
if this is ever redone:
- `RotatorHW::jogMicrosteps()` (the debug jog used by every full-step-scale
  capture script) did not disengage the continuous position-holding task
  (this session's `holdTask()` feature) before moving the motor. A long
  sequence of jogs (a real calibration sweep) never updates the hold
  target, so the hold task kept trying to correct back toward wherever it
  was holding *before* the sweep started, physically fighting the sweep's
  own motion the whole time it ran - corrupted an entire ~12-minute capture
  before this was caught (the Hall sensor stayed permanently "active" and
  the sensor reading got stuck for long stretches, both symptoms of the
  motor barely actually moving). Fixed by disengaging holding at the start
  of `jogMicrosteps()`, matching every other raw-motion function.
- `fit_fourier_against_reference()`'s theta must be computed from the RAW
  sensor reading, not from the camera - see the least-squares section
  below for why, and for a separate, independent bug (a single un-despiked
  ~90 deg camera tracking glitch) that made an early attempt at re-deriving
  this look far worse than it was.

**Verified end-to-end** (Alpaca `MoveAbsolute`/`Move` + independent camera
ground truth over 50 random positions, `scripts/alpaca_random_sweep.py`):
RMS improved from 0.104-0.166 deg (smooth model alone, either fitting
method) to **0.091 deg RMS / 0.156 deg peak** with the table applied - the
best closed-loop accuracy this project has measured through the firmware's
own `refineToTarget()`/Alpaca path (see "Two closed-loop paths" below for
why this isn't directly comparable to the older Python-PI-controller
figure further down).

### Does a smooth fit at a higher order replace the table? No.

Tested directly (`scripts/fullstep_order_sweep_experiment.py`): fit
`camera_angle_analyze.py`'s model at orders 1 through 199 on one measured
revolution, score the held-out residual against an *independently
measured second revolution*. Getting this measurement right took two
false starts worth recording:
- Using the camera's own phase as the fit's theta (as `fit_fourier_against_
  reference()` already does for the smooth low-order model) works for
  *that* model, but is wrong for evaluating what gets deployed: at runtime
  `correctSensorReading()` only ever has the raw sensor reading to compute
  theta from, and a fixed alignment mismatch between "camera phase" and
  "raw phase" gets amplified by the harmonic order `k`, scrambling higher
  orders long before it visibly affects order 1-4. Franz's fix: index the
  fit by the raw sensor reading itself (exactly what deployment does),
  fitting against the camera measurement only as the *target*, never as
  the phase argument - a wrong additive offset there only ever shifts C0
  (already re-derived from `gotoMechanicalZero()` regardless), never the
  harmonics.
- Once that was right, a single un-despiked ~90 deg camera corner-tracking
  glitch (the same "large per-frame step" cases `track_rotation()` already
  warns about) was still enough to wreck a least-squares fit outright - one
  bad point at ~1300+ counts off dominates a squared-error objective.
  Excluding the two flagged frames fixed it.

With both fixed, the held-out residual is essentially **flat from order 4
through order 150** (~0.755-0.855 deg motor-shaft, full-step resolution),
only degrading at order 199 (399 parameters for 400 points - classic
overfitting at the Nyquist edge). Order 7 visually tracks the measured
curve's sharp peak and small secondary bumps well (not a sine - looks like
a ramp with smaller harmonics riding on it, matching a visual Franz
independently called as "sawtooth plus sine"), but earns no measurable
held-out advantage over the already-deployed order 4. This refines (not
contradicts) the "higher orders (2-6) got worse again" finding further
above - that earlier test may have suffered a version of the same
phase-basis issue - but the practical conclusion is the same: don't chase
higher harmonic orders here, the full-step table above is what actually
works.

### Does per-segment calibration help? No.

Franz's hypothesis: if the belt pulley driving the output stage is itself
eccentric or unevenly deformed, a fixed motor-shaft angle might not behave
identically depending which of the 10 motor revolutions (segments) per
output revolution it falls in - in which case ten segment-specific AS5600
fits should out-perform one global fit. Tested on the existing
full-revolution sweep (`scripts/segment_calibration_experiment.py`): fit
each segment on half its points (even index), score on the other half (odd
index) - a held-out design specifically to guard against 10x the
parameters looking better purely by fitting noise. Result: the segmented
fit was *worse* than the global one on held-out data (RMS 0.377 deg vs
0.249 deg), and no individual segment beat the global fit convincingly.
Ruled out as an explanation for this project's remaining residual.

### Camera measurement noise floor

Never directly measured before this pass: `scripts/
camera_repeatability_test.py` photographs a completely unmoving rotator
repeatedly (30 frames) and runs the same corner-tracking analysis
everything else in this project relies on. Result: RMS=0.0022 deg,
peak-to-peak=0.009 deg - two orders of magnitude below every real-world
residual this project has measured. The camera has never been the
limiting factor; every residual documented in this file is a real
property of the rotator/sensor/calibration, not a measurement artifact.

## Closed-loop PI position control

**Two closed-loop paths now exist in this project, not directly comparable:**
this section's `scripts/pi_position_control.py` is a Python-orchestrated
prototype (drives the debug jog endpoint directly, does its own PI math on
the host) - it produced the 0.037 deg/0.076 deg figure in "Backlash and
100-point random validation" below. Since then, that design was ported into
the firmware itself (`RotatorHW::refineToTarget()`, run after every
`Move`/`MoveAbsolute`/`MoveMechanical`/`Sync`) and extended with continuous
position holding after a move settles (`RotatorHW::holdTask()`). The
full-step lookup table's 0.091 deg/0.156 deg verification above went
through *that* path, driven by genuine Alpaca calls
(`scripts/alpaca_random_sweep.py`), not the Python prototype - a real,
different measurement, not a regression from 0.037 deg.

The insight that mattered most: instead of chasing an increasingly complex
motor/gearbox model (cogging, position-dependent full-step gain that varies
+/-25% around the revolution, weak inter-step wobble correlation), close the
loop. `scripts/pi_position_control.py` moves toward a target, re-measures
(Kalman-filtered AS5600 reading, `scripts/angle_filter_lab.py`'s
`AngleKalman1D`), and corrects - absorbing whatever the true open-loop gain
turns out to be at that spot, without needing to predict it.

First live test overshot badly (16 iterations, visible ringing) from
classic **integral windup**: the large initial error entered the integral
term and dominated for many iterations after the proportional term was
already small. Fixed with conditional integration (only integrate while
`|error| < 0.05 deg`) - a standard anti-windup technique, not a hardware
issue. After the fix: 1-3 iterations, confirmed final error 0.004-0.007 deg.

## Backlash and 100-point random validation

`scripts/backlash_and_random_validation.py` + `scripts/backlash_camera_analyze.py`:
approach a target from a fast open-loop overshoot then a precise PI
convergence, from a chosen direction (cw/ccw), photograph, repeat.

- **Dedicated backlash test** (8 positions, cw+ccw each): mean 0.015 deg,
  spread (RMS) 0.019 deg, peak 0.052 deg - at or below the camera's own noise
  floor, so best read as "backlash, if present at all, is under ~0.02-0.05 deg,"
  not a precisely resolved value.
- **100 random targets, random cw/ccw direction each, independent camera
  verification**: overall RMS 0.037 deg, peak 0.076 deg against the pure
  open-loop commanded odometer - the best end-to-end accuracy number this
  project has produced. A directional bias (cw mean +0.010 deg, ccw mean
  +0.045 deg, difference -0.034 deg) is statistically solid at this sample
  size (~8 standard errors from zero) and refines the smaller-sample
  backlash test's estimate.

## What's deferred

- ~~The full-step lookup-table firmware change~~ - **done, 2026-09-11** -
  see "Full-step lookup table: implemented and verified" above.
- Verifying camera FOV/focus distance formally (mount is still adjustable).
- SpreadCycle re-tuning (HSTRT/HEND/TBL) now that current is fixed - not
  revisited this pass, since closed-loop control looks like it matters more
  than the open-loop waveform shape.

## Tools produced this pass

| Script | Purpose |
|---|---|
| `scripts/camera_angle_sweep.py` | drives a full output revolution, photographs each point |
| `scripts/camera_angle_analyze.py` | corner tracking, camera-vs-AS5600 comparison, camera-referenced refit |
| `scripts/camera_eccentricity_calibrate.py` | fits/removes target-mounting eccentricity from 10 full-step-aligned probe points |
| `scripts/fullstep_table.py` | builds (and despikes) a 400-entry per-full-step correction table - data only, not wired into firmware |
| `scripts/pi_position_control.py` | closed-loop PI position control with Kalman-filtered feedback |
| `scripts/backlash_and_random_validation.py` | directional (cw/ccw) approach + camera capture, for backlash and broad accuracy checks |
| `scripts/backlash_camera_analyze.py` | analyzes the above: per-position backlash, cw/ccw statistics |
| `../RotatorCam/generate_pattern.py` | printable checkerboard target (separate repo) |

### Added 2026-09-11 (full-step table + verification tooling)

| Script | Purpose |
|---|---|
| `scripts/camera_fullstep_sweep.py` | camera-referenced version of `fullstep-accuracy`: one photo per full step, >=2 motor revolutions |
| `scripts/camera_fullstep_table.py` | builds the full-step table from that capture, referenced against the currently-deployed model |
| `scripts/upload_fullstep_table.py` | pushes a table to `/api/calibration/fullstep-table`, confirms by read-back |
| `scripts/upload_angle_calibration.py` | pushes C0/A[]/B[] to `/api/calibration/coefficients`, confirms by read-back |
| `scripts/alpaca_client.py` | minimal stdlib ASCOM Alpaca REST client - the one thing every Alpaca-only tool below builds on |
| `scripts/alpaca_conformance.py` | 20-check Alpaca protocol conformance suite (error codes, gating, motion-limit guarantees) |
| `scripts/alpaca_random_sweep.py` | 50 random Alpaca `Move()` calls + independent camera verification - the closed-loop accuracy check this pass's numbers come from |
| `scripts/camera_repeatability_test.py` | isolates the camera+corner-detection pipeline's own noise floor (rotator held still) |
| `scripts/fullstep_order_sweep_experiment.py` | held-out (rev-vs-rev) test of whether a higher-order smooth fit can replace the full-step table |
| `scripts/segment_calibration_experiment.py` | held-out (odd/even split) test of per-motor-segment AS5600 fits vs. one global fit |

Requires `numpy`/`opencv-python-headless` in a separate venv for anything
that touches images - see `scripts/requirements-camera-analysis.txt`. Deliberately
not added to the ESP-IDF dev container's pinned Python environment.

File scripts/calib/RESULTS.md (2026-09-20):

# Rotator angle accuracy: what was measured, 2026-09-18/19

A from-scratch calibration of the angle chain on the one unit, measured with
the output-shaft chessboard camera as an independent reference. Every number
here is live hardware; none is simulated.

## Summary

The firmware already positions the **motor shaft** to better than 0.01
degrees. Everything that stops the **output shaft** from getting there sits
downstream of the 10:1 reduction, where the AS5600 cannot see it.

| | |
|---|---|
| firmware closed loop, sensor against Alpaca target | **4.5 mdeg rms**, max 13 |
| what a user actually gets, 200 random targets | **52.5 mdeg rms**, max 120 |
| of which: direction-dependent, on random targets | 64 mdeg peak-to-peak |
| that, after a one-sided approach in firmware | 38.7 mdeg |
| lost motion on reversal, measured directly | ~89 mdeg |
| irreducible position hysteresis, any approach length | ~25-30 mdeg |
| of which: output error as a function of position | ~36 mdeg rms |
| after correcting for both, measured again | **22.5 mdeg rms**, max 54 |
| run-to-run repeatability of the position-dependent error | **10.7 mdeg** |

The last line is the hard floor: two independent sweeps of the same error
correlate at +0.955 but differ by 10.7 mdeg rms, of which 3.3 mdeg is camera
noise. About 10 mdeg of the mechanics simply does not repeat.

## Two firmware-level findings

**The AS5600's ANGLE register has a dead band at its wrap.** The chip applies
a documented ~10 LSB hysteresis at the limit of its 360-degree range.
Measured with a one-count fine sweep: travelling upwards the output stuck at
exactly 4095 for 275 microsteps - eleven counts of real motion reported as
none - then jumped straight to 11, while the same crossing downwards was
smooth. That is 0.105 output degrees per motor revolution carrying no
position information, and no smooth correction model can represent it.
`RotatorHW::readAngleSafe()` now reads RAW ANGLE (0x0C) instead. Verified on
the flashed build: thirty commanded one-count steps across the wrap advance
the sensor by 30.875 counts, against eleven counts of motion producing no
output at all before.

The fix paid twice. The raw register dithers by +/-1 LSB where the ANGLE
register's internal filtering suppressed it - at rest the old path returned
the identical integer twenty times in a row, so averaging bought nothing.
With dither, averaging yields real sub-count resolution, and forward
repeatability improved from 2.29 to 1.31 mdeg.

**The stored full-step table was actively harmful.** The 400-entry residual
table on the device spanned -17.4 to +22.8 counts - 353 mdeg peak to peak -
and had been fitted against the previous correction and the old register. It
was injecting up to 222 mdeg of drift. Cleared; the previous contents are in
`backup_fullstep_table.json`.

## Sensor characteristic

400 support points, one per full step, over exactly one motor revolution;
three passes (forward, reverse, forward).

| | |
|---|---|
| uncorrected error | 0.225 deg peak-to-peak |
| closure over one revolution | <= 0.5 counts - no lost steps |
| forward repeatability | 0.149 counts = 1.31 mdeg output |
| residual after the order-5 fit | 0.347 counts = **3.0 mdeg output** |
| direction hysteresis at the motor shaft | 3.17 counts = 27.9 mdeg, constant across the revolution |

Harmonic amplitudes in counts: k1 8.58, k2 4.75, k3 1.33, k4 3.27, k5 0.60,
and from k6 on 0.02-0.03 - noise. **Order 5 is where the data stops
improving**; order 7 buys 0.02 counts. The device's stored format is KMAX = 4
(`main/RotatorHW.h`), which costs 4.8 mdeg instead of 3.0; raising it is a
persistent-format change and was not done.

The fit reproduced across two sweeps taken hours apart to within a few
percent on every harmonic, so it is the machine's characteristic and not a
fit to noise.

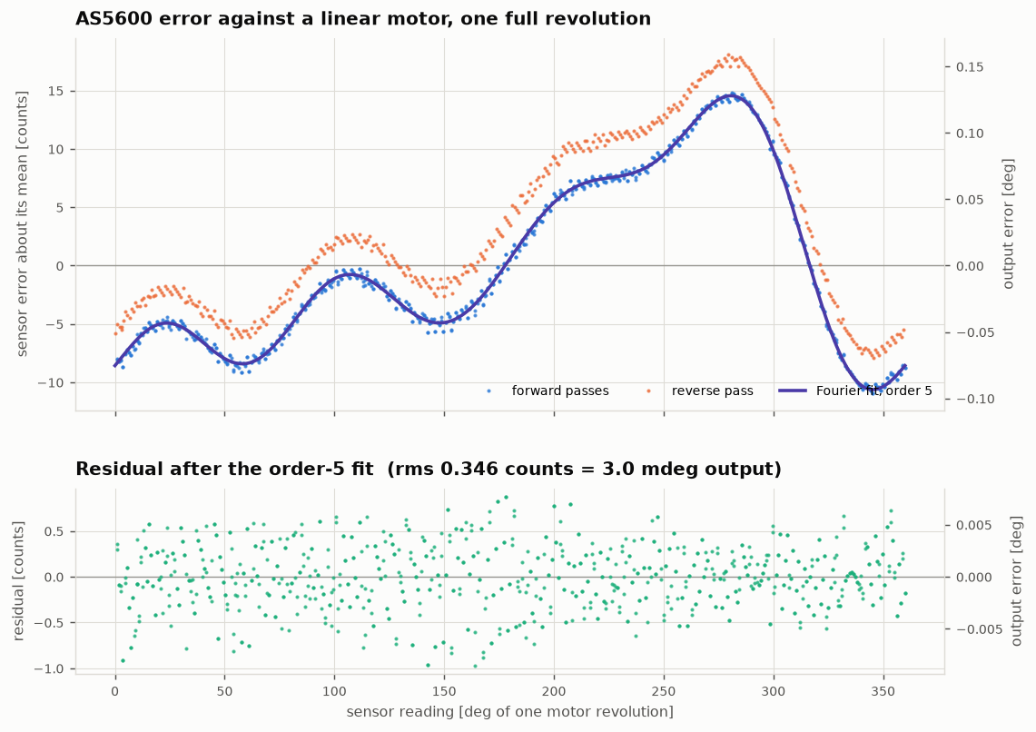
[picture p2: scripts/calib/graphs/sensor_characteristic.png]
sensor characteristic

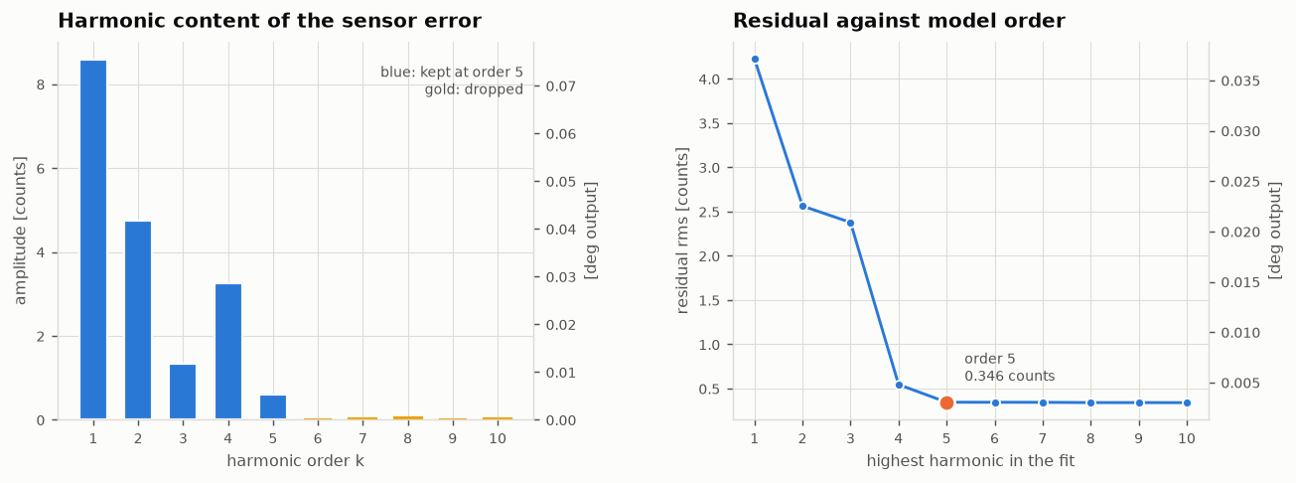
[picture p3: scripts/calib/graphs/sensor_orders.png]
model order

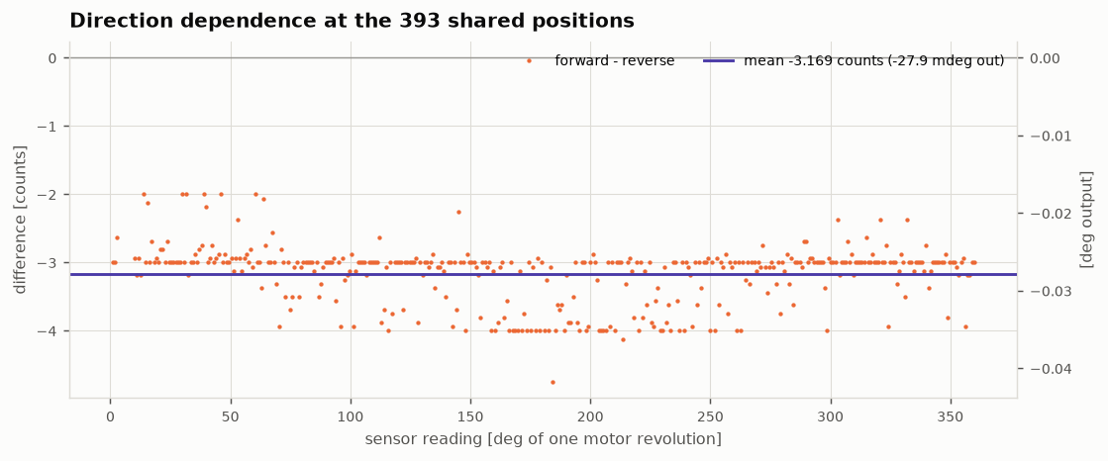
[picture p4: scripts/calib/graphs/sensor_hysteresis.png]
hysteresis


## Control law

P, PI, PD and PID compared on the real machine over the same six targets,
4 mdeg tolerance:

| | final error rms | iterations |
|---|---|---|
| P | 2.26 mdeg | 1.5 |
| PI | 2.52 mdeg | 3.0 |
| PD | 2.20 mdeg | 2.3 |
| PID | 2.03 mdeg | 2.7 |

All four land in the same place; P gets there fastest. This is structural
rather than a matter of tuning: a commanded microstep *is* the movement, so
the plant has neither dynamics for a derivative term to damp nor a standing
offset for an integral term to remove. A small integral term still earns its
place against hysteresis, which is what the firmware already does.

## Microstepping is not worth modelling

One microstep is 4096/(400*256) = 0.04 sensor counts, so the AS5600 cannot
resolve one at all. It can be reached statistically: sample the same
microstep *phase* at many different full steps, where each sits at a
different sub-count offset, and the quantisation decorrelates across them.
961 points over 60 full steps, 16 phases each, against the corrected sensor:

| phase, of 256 | mean deviation |
|---|---|
| spread across all 16 phases | **1.73 mdeg peak-to-peak** |
| uncertainty per phase bin | 0.54 mdeg |

With sixteen bins at 0.54 mdeg each, a 1.7 mdeg spread is about what noise
alone produces. **The TMC2209's microstepping is linear to below 2 mdeg at
the output** - two orders of magnitude under the backlash and one under the
sensor model's own residual. There is nothing here worth correcting, and a
microstep model would be fitting noise.

## What the sensor cannot see

The AS5600 is on the motor shaft. Two sweeps over a full output revolution,
at deliberately different step spacings so neither run's aliasing could be
mistaken for signal:

| | run 1 | run 2 |
|---|---|---|
| rms | 37.9 mdeg | 36.3 mdeg |
| peak-to-peak | 159 mdeg | 144 mdeg |
| dominant harmonic (2 cycles/output rev) | 42.0 mdeg at phase 1.4 deg | 41.3 mdeg at phase **2.2 deg** |
| once per motor revolution (k=10) | 19.7 mdeg | 22.1 mdeg |

Agreeing to 0.8 degrees of phase on the dominant term makes this a fixed
property of the machine.

It was checked for being a camera artefact and is not. A simulated 3-degree
board tilt produces 2.9 mdeg of angle error with 48e-4 anisotropy, against
41 mdeg with 19e-4 observed - off by a factor of twenty. And splitting the
board into inner and outer corners, whose radii differ threefold, gives 46.4
and 38.9 mdeg for the same term; a geometry artefact would scale with radius
and this does not.

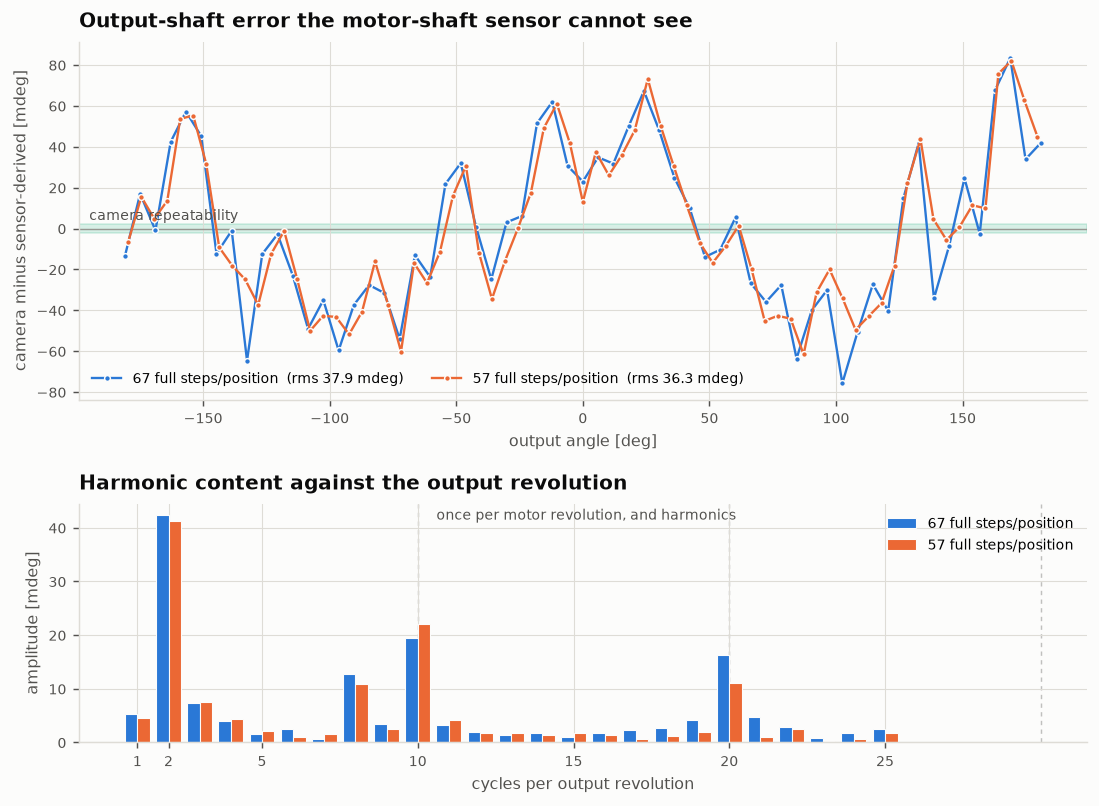
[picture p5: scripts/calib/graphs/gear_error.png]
gear error


## End-to-end test run

200 random targets over ASCOM Alpaca - the user's own path, no debug
endpoints - measured against the chessboard.

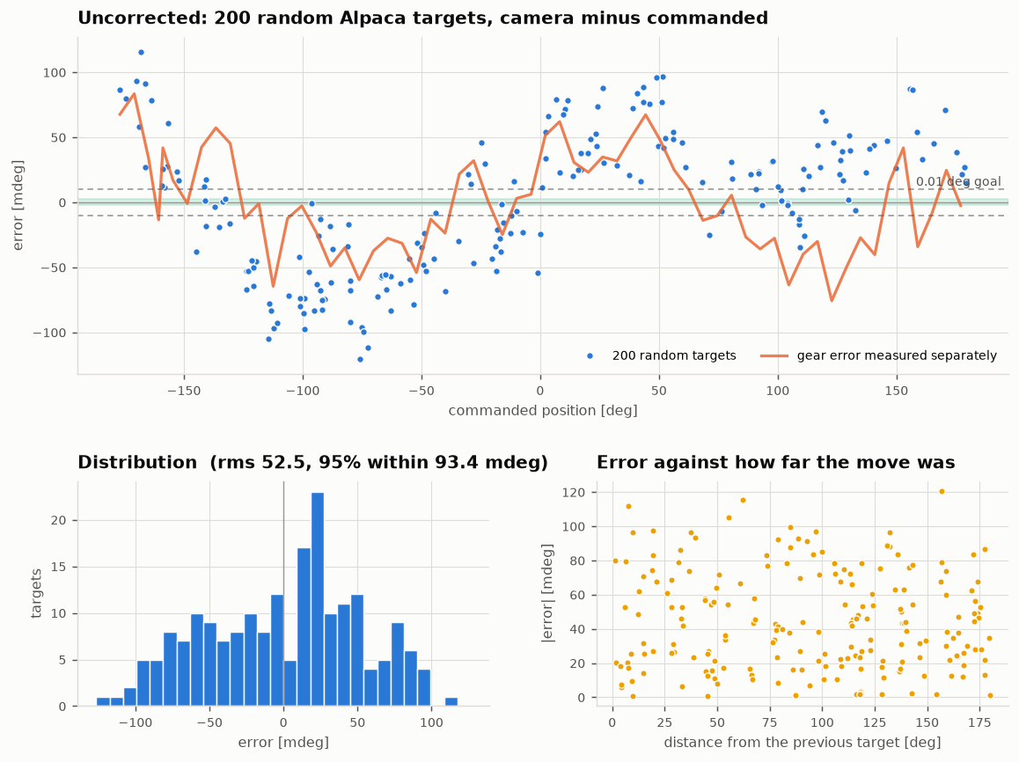
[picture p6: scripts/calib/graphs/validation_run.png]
validation run


The separately measured gear-error curve lies through the middle of the
scatter, and the two bands around it are the backlash. The histogram is
bimodal for the same reason.

Decomposed, scored by 5-fold cross-validation on targets the model never saw:

| model | held-out residual |
|---|---|
| uncorrected | 52.5 mdeg |
| direction term only | 42.6 mdeg |
| output angle k=1-4 + direction | 21.9 mdeg |
| output angle k=1-4 + motor phase k=1-5 + direction | **15.1 mdeg** |

The error has two separable parts: one over the **output** angle, which is
the gearing, and one over the phase within a **motor** revolution, which is
what the 400-entry full-step table is indexed by. More harmonics do not help
- they overfit, and the held-out figure gets worse.

## The correction, applied and measured again

The decomposition above is a fit, so it was put to the only test that counts:
predict, apply, measure again. The same 100 targets were re-run with the
correction pre-compensated into each command and every target approached
from the same side.

| | uncorrected | corrected |
|---|---|---|
| firmware loop, sensor against what it was commanded | 4.5 mdeg rms | 4.0 mdeg rms |
| camera against target | **52.5 mdeg rms**, max 120 | **22.5 mdeg rms**, max 54 |
| within 10 mdeg | 9 % | **32 %** |
| within 20 mdeg | 22 % | **61 %** |
| backlash split | 63.7 mdeg | 33.3 mdeg |

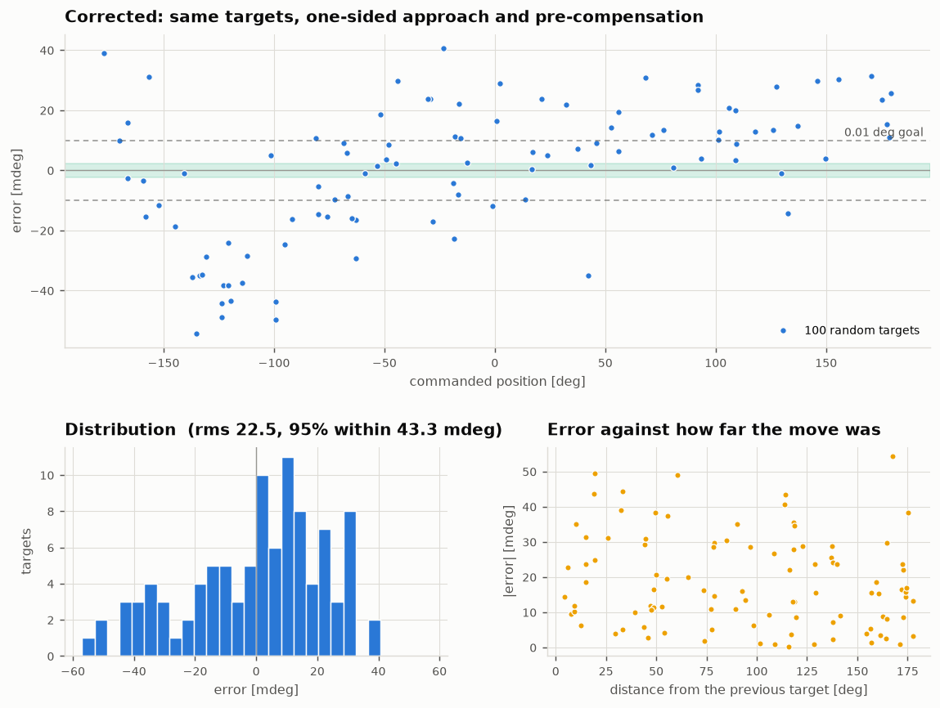
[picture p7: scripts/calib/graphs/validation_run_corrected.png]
corrected run


Less than half the error, from a model fitted on a different set of targets.
The firmware's loop is untouched at 4 mdeg, confirming the correction acts
where it was meant to.

Two things it did not fully deliver. The backlash split halved rather than
vanished: the one-sided approach controls the last move *this script*
commands, but the firmware's own closed loop then makes its final
corrections in whichever direction it needs, so the last motion the gearbox
actually sees is not controlled. Removing the rest means making the
firmware's final approach directional. And the residual still carries
structure - visibly so between -130 and -100 degrees - which is where the
drift below comes in.

## One-sided approach, built into the firmware

`refineToTarget()` now finishes every approach moving in the positive
direction: it backs off to 0.15 degrees below the target first whenever it
would otherwise have to correct downwards, and treats an overshoot the same
way. `holdTask()` keeps the rule up for as long as the hold lasts - a
downward correction there would hand the gear train straight back across the
slack, so inside the margin it does nothing at all (and freezes its integral
with it), and past the margin it re-approaches from below.

Confirmed in the device log over 40 commanded moves: 39 back-offs, no
overshoots, and of six hold corrections not one was negative.

Measured with the camera, against the uncorrected baseline:

| | bidirectional | one-sided |
|---|---|---|
| camera against target | 52.5 mdeg rms | **38.8 mdeg rms** |
| max | 120 mdeg | 80 mdeg |
| direction split | 63.7 mdeg | 38.7 mdeg |
| within 10 mdeg | 9 % | 20 % |

It removes what is removable, and stops there. Reaching one target sixteen
times, eight from 40 degrees below and eight from 40 degrees above - with
the log confirming all thirty-two approaches were identical, one back-off
and two corrections each - still left a **30.3 mdeg split**, repeatable to
under 5 mdeg within each group.

That remainder is not backlash. Backlash is taken up by a long enough
approach and this is not: driving to one fixed motor position by raw
microsteps, once after a 5-degree positive run-up and once after reversing
and approaching positively by 0.15, 0.30, 0.60 and 1.20 degrees, left the
output 31, 20, 30 and 24 mdeg away respectively - flat against approach
length. A separate reversal measurement put the lost motion at about 89
mdeg and showed the output moving in ~70 mdeg jumps rather than smoothly.

So the output shaft rests anywhere within a roughly 25-30 mdeg band, and
which end of it depends on history in a way no approach discipline fixes.
Stiction in the output stage is the obvious suspect. It is mechanical, and
it is a large part of both the ~10 mdeg floor and of what is left after
correction.

## The correction is not stable over hours

The 200-target run took two hours, and its residual drifts with elapsed
time: correlation +0.54, about +25 mdeg end to end. Splitting the run:

| | residual |
|---|---|
| whole run, best model | 13.7 mdeg |
| same model plus a linear time term | 12.2 mdeg held-out |
| first half alone | 10.7 mdeg |
| second half alone | 10.9 mdeg |
| first half's model applied to the second half | 14.1 mdeg |

Within a shorter window the error is **10.8 mdeg** - which is the same
figure the two independent gear sweeps gave for run-to-run repeatability,
reached by a completely different route.

What drifts cannot be separated with a single reference: a slow movement of
the camera rig and one of the rotator rig look identical, and two hours of
motor running warms both. Either way, a calibration run should be short, and
a correction should not be assumed good for a whole night without checking.

## The routine now runs on the device

The host-driven sweep above is what `calibrateAngleSensor()` does as of
v0.10.0, in-process and camera-free, reachable at
`GET /api/calibration/angle/stream`. Three things changed against the old
one, all of them measured rather than reasoned:

- it never touches the driver's microstep resolution. The old routine
  switched to full-step mode, which leaves FastAccelStepper's position
  counter undercounting by up to 256x - forcing a re-home afterwards - and
  is the prime suspect for the hangs that killed four of four live attempts;
- it settles 250 ms and averages 16 samples, where the old one settled 20 ms.
  That is almost certainly why moving at the normal resolution had been
  judged "measurably worse" once before: 20 ms is far too short for a
  256-microstep move to stop ringing;
- the fit is least squares against the **absolute step counter**, not a 2/N
  Fourier projection against the sweep's own first point. The old anchor is
  what made every recalibration silently move the mechanical zero.

Run on the device, against the same machine the host campaign measured:

| | host campaign | in firmware |
|---|---|---|
| residual | 0.347 counts (3.05 mdeg) | **0.415 counts (3.65 mdeg)** |
| closure over a revolution | <= 0.5 counts | -0.875 counts |
| A1..A5 | -4.04 -4.69 -0.70 0.70 0.15 | -4.30 -4.58 -0.68 0.74 0.21 |
| B1..B5 | -7.57 0.80 1.13 3.20 0.58 | -7.52 0.78 0.96 3.23 0.60 |

Every harmonic agrees to within a few percent, and the "before" figure the
run reported - 0.660 counts for the migrated order-4 correction - is what
order 4 measured on the bench.

## Three stored things that have to agree

The coefficients, the mechanical-zero target and the full-step table are not
independent: the zero is stored as a *corrected* sensor value and the table
is indexed by one, so both are expressed in terms of whatever correction was
in force when they were measured. Replacing the coefficients does not make
them noisily wrong, it makes them silently wrong - which is how a table
spanning 353 mdeg came to be sitting on this device against a correction it
no longer belonged to.

Every write of the coefficients now bumps a generation, the two derived
artefacts are stamped with the generation they were measured against, and a
mismatch is reported at load. `GET /api/calibration/status` answers it:

```json
{"generation":3,"kmax":5,"zeroStale":false,
 "fullStepTableStale":false,"zeroPosSensorValue":780,"consistent":true}
```

A stale table is dropped rather than applied - all-zero is a no-op, a
mismatched one is a confident wrong answer - while a stale zero is reported
but still used, since dropping it would leave homing with nothing.

Running this on the device turned up one more thing. Its stored mechanical
zero was **27**, the hand-measured constant that predates any calibration,
and it had never been re-derived. Measured properly it is **581** - so the
machine's absolute zero moves by about 4.9 degrees, and every Alpaca
position it reported before this was offset by that much.

One loose end there: the first run of that measurement returned 780 and
every run since has returned 581, three times bit-identical, with homing
landing on 578.3 against a target of 578. The weight of evidence is with
581 and the machine is self-consistent on it, but the single 780 is
unexplained - worth a second look before trusting the absolute zero to
better than a degree.

## The device can now run the output calibration itself

As of v0.11.0 there is a button for it, and a field for the address to ask.
The split is deliberate: the rotator knows how to move, fit and store; it
does no image processing at all and just GETs a number from
`Configuration::getCameraAngleSource()`.

That is not squeamishness about the work. Putting the vision on the rotator
would mean pulling a 270 KB JPEG over WiFi and decoding it into 1.9 MB of
PSRAM to reach pixels another device already holds, plus a chessboard
detector - the largest and least testable code in the project. Memory and
flash would have been fine (tjpgd is in the ESP32-S3 ROM, 600 KB of app
partition free, 8.26 MB of contiguous PSRAM); the detector is the problem.
Template matching was tried as a substitute on 71 already-captured frames
and measured 1679 mdeg rms against the chessboard pipeline - 460 times too
coarse - so it is not the easy way out it looks like.

`scripts/calib/angle_service.py` answers the question today, with the same
homography-ratio estimator as the rest of the campaign; RotatorCam should
answer it eventually, since it already has the frame.

The correction is fed forward onto the commanded angle only, never onto the
reported position - the loop drives the sensor, and the sensor cannot see
the gearing, so correcting what it reads would make it chase itself. It is
stamped with the sensor-calibration generation like the zero and the
full-step table, and dropped if that changes.

Two things the first live run taught, both fixed: progress has to count
positions *attempted*, or a run against an unreachable source is
indistinguishable from a hung one; and the run has to give up after a few
failures in a row, because an address that silently drops packets turns 164
positions into 164 timeouts.

That run also exposed something older and worse. All three calibration
routines used to block the HTTP server for their whole duration - ESP-IDF's
httpd serves every socket from one task, and an SSE handler that streams
progress for half an hour holds it. Not just its own connection: the status
endpoint, the Alpaca routes, everything. As of v0.12.0 the request is handed
to a worker with `httpd_req_async_handler_begin()`, so the handler returns
at once and the server goes back to its select loop; the wire protocol is
unchanged. Measured on the device: **12 of 12 status probes answered in
94-193 ms while a calibration was running**, where before it answered
nothing at all.

## Answering the original question

A user with a fresh unit, calibrating without a camera, can correct the
sensor characteristic and nothing else. That leaves ~37 mdeg of position
error plus 64 mdeg peak-to-peak of backlash.

Two things change that:

- **Approach every target from the same side.** Now in the firmware
  (`BACKLASH_APPROACH_DEG` in `RotatorHW.cpp`), costing one extra 0.15 degree
  move: 52.5 mdeg down to 38.8. It does not remove the whole split, because
  about 25-30 mdeg of the hysteresis is stiction rather than backlash and no
  approach length touches it.
- **Measure the output error once per unit with a camera**, and correct on
  both indices. Measured end to end, that took 52.5 mdeg down to 22.5.

So 0.01 degrees is the right order of magnitude to aim at, but not reliably
beaten: the floor is ~10 mdeg of mechanics that does not repeat, plus a slow
drift on top, and it is mechanical rather than instrumental. Whether the position-dependent part is
per-unit or shared across identical builds is the open question - if it is
largely the motor rather than this particular gearbox, a correction measured
once could ship with the firmware. That needs a second unit to settle.

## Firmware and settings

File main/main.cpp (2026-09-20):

#include <Arduino.h>
#include <string.h>
extern "C"
{
#include "freertos/FreeRTOS.h"
#include "freertos/task.h"
#include "freertos/queue.h"
#include "esp_log.h"
#include "esp_netif.h"
#include "esp_netif_types.h"
#include "nvs_flash.h"
#include "nvs.h"
#include "esp_littlefs.h"
#include "esp_wifi.h"
#include "tinyusb.h"
#include "tinyusb_net.h"
#include "tusb.h"
#include "tusb_cdc_acm.h"
#include "tusb_console.h"
#include "esp_mac.h"
#include "esp_http_server.h"
#include "lwip/ip4_addr.h"
#include "ftp.h"
#include "usb_descconfig.h"
#include "OTAUpdate.h"
#include "LogBuffer.h"
#include "FileRoutes.h"
#include "NvsRoutes.h"
}
#include <dirent.h>
#include <stdio.h>

#include "Configuration.hpp"
#include "WebServer.h"
#include "WifiManager.h"
#include "RotatorApi.h"
#include "RotatorHW.h"
#include "ExpertLock.h"

static const char *TAG = "main";
//QueueHandle_t angleUpdateQueue = nullptr;

extern "C" size_t rotator_get_sketch_size(void)
{
    return ESP.getSketchSize();
}


// the port of the Alpaca Server
#define ALPACA_SERVER_PORT 80

// ----------------------------------------------------------------
// ------ Helper functions to set up the ASCOM Alpaca device ------
// ----------------------------------------------------------------

RotatorApi &get_rotator_api()
{
    static RotatorApi rotatorApi(RotatorHW::getInstance());
    return rotatorApi;
}

std::vector<AlpacaServer::Device *> &get_devices()
{
    static std::vector<AlpacaServer::Device *> devices{&get_rotator_api()};
    return devices;
}

AlpacaServer::Api &get_api()
{
    static AlpacaServer::Api api(
        get_devices(),
        "Rotator",
        "Astro Geeks Alpaca Server",
        "Astro Geeks",
        ROTATOR_VERSION,
        "Munich");
    return api;
}

extern "C" void app_main(void)
{
    // First thing, before anything else has a chance to log: the lines from
    // the first two seconds of boot are the ones nobody is ever watching for.
    log_buffer_init();

    initArduino();

    // 1) NVS required by WiFi/Net stack
    ESP_LOGI(TAG, "Initializing NVS...");
    esp_err_t ret = nvs_flash_init();
    if (ret == ESP_ERR_NVS_NO_FREE_PAGES || ret == ESP_ERR_NVS_NEW_VERSION_FOUND)
    {
        ESP_ERROR_CHECK(nvs_flash_erase());
        ret = nvs_flash_init();
    }
    ESP_ERROR_CHECK(ret);

    // also read in configuration from flash disk
    auto &cfg = Configuration::getInstance();

    // 2) NetIF
    ESP_LOGI(TAG, "Initializing netif...");
    ESP_ERROR_CHECK(esp_netif_init());
    ESP_ERROR_CHECK(esp_event_loop_create_default());

    // 3) TinyUSB stack
    ESP_LOGI(TAG, "Installing TinyUSB driver...");
    tinyusb_config_t tusb_cfg = {
        .device_descriptor = &descriptor_device,
        .string_descriptor = descriptor_strings,
        .external_phy = false,
        .configuration_descriptor = descriptor_configuration};
    ESP_ERROR_CHECK(tinyusb_driver_install(&tusb_cfg));

    // 4) CDC for logging
    ESP_LOGI(TAG, "Initializing CDC ACM...");
    tinyusb_config_cdcacm_t amc_cfg = {
        .usb_dev = TINYUSB_USBDEV_0,
        .cdc_port = TINYUSB_CDC_ACM_0,
        .rx_unread_buf_sz = 128,
    };
    ESP_ERROR_CHECK(tusb_cdc_acm_init(&amc_cfg));
    esp_tusb_init_console(TINYUSB_CDC_ACM_0);

    // 5) RNDIS network interface
    // Set IP from config file
    setup_usb_rndis_ip(cfg.getIPAddressInt(), cfg.getIPAddressInt(), cfg.getNetmaskInt());
    // Set mac address form config file
    setup_usb_rndis_mac(cfg.getMACAddress().data());
    // the RNDIS netif is brought up here
    setup_usb_rndis_netif();
    ESP_LOGI(TAG, "TinyUSB CDC and RNDIS initialized!");

    // 6) Wifi init
    wifi_manager_init();

    // 7) HTTP server
    httpd_config_t http_cfg = HTTPD_DEFAULT_CONFIG();
    http_cfg.server_port = ALPACA_SERVER_PORT;
    http_cfg.uri_match_fn = httpd_uri_match_wildcard;
    // The Alpaca common+Rotator routes, WebServer's own routes, OTA, expert
    // lock, file/NVS browsing and the log endpoint together already fill
    // this close to exactly 64 - a live device panicked with
    // ESP_ERR_HTTPD_HANDLERS_FULL registering the very last (wildcard)
    // handler after just one more debug route was added. Sized with real
    // headroom, not just enough for today's count.
    http_cfg.max_uri_handlers = 96;
    http_cfg.stack_size = 16384;
    // A calibration run now hands its request to a worker task and keeps the
    // socket for the whole run - over half an hour for the output-angle one.
    // Without LRU purging, a couple of abandoned browser tabs on top of that
    // fill max_open_sockets and the server stops accepting anything at all.
    // Safe alongside the async handover: httpd_sess.c's lowest-LRU search
    // explicitly skips sessions marked for_async_req, so the run's own
    // socket is never the one reclaimed.
    http_cfg.lru_purge_enable = true;
    // The default five seconds is not enough for a filesystem upload. That
    // handler erases the whole 10 MB littlefs partition in one call before
    // it reads the rest of the body, and the erase alone outlasts the
    // default - a live upload on 2026-09-20 timed out mid-write and left
    // the device with an erased partition and no web UI at all, which is a
    // far worse state than a refused upload. Twenty seconds covers the
    // erase with room to spare; a client that stalls that long is now
    // reclaimable anyway, thanks to the LRU purge above.
    http_cfg.recv_wait_timeout = 20;
    httpd_handle_t server = nullptr;
    ESP_ERROR_CHECK(httpd_start(&server, &http_cfg));

    // 8) Over the Air Update registration
    expert_lock_init();
    expert_lock_register_routes(server);
    log_buffer_register_routes(server);
    file_routes_register(server);
    nvs_routes_register(server);
    register_ota_update_uri(server);

    // 9) Device and Alpaca Server
    RotatorHW::getInstance().begin();
    get_api().register_routes(server);

    // 10) Start tasks that update the GUI automatically
    xTaskCreate(angle_producer_task,  "angProd", 4096, NULL, 2, NULL);
    xTaskCreate(angle_event_broadcast, "wsBrdc", 4096, NULL, 2, NULL);

    // 11) Register all webserver handles
    register_web_handles(server);

    // 12) Alpaca discovery daemon
    alpaca_server_discovery_start(ALPACA_SERVER_PORT);

    // 13) Start ftp server
    xTaskCreate(ftp_task, "FTP", 1024 * 6, NULL, 2, NULL);

    // 14) Move to mechanical zero
    RotatorHW::getInstance().gotoMechanicalZero();


    while (1)
    {
        vTaskDelay(100 / portTICK_PERIOD_MS);
        //angles.angle = RotatorHW::getInstance().getPosition();
        //angles.angle = fmod(angles.angle + 1.0, 360.0);
        //angles.mechAngle = 10.0;
        //xQueueOverwrite(angleUpdateQueue, &angles);
    }
}

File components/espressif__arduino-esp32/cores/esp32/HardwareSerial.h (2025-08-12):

/*
 HardwareSerial.h - Hardware serial library for Wiring
 Copyright (c) 2006 Nicholas Zambetti.  All right reserved.

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
 Modified 28 September 2010 by Mark Sproul
 Modified 14 August 2012 by Alarus
 Modified 3 December 2013 by Matthijs Kooijman
 Modified 18 December 2014 by Ivan Grokhotkov (esp8266 platform support)
 Modified 31 March 2015 by Markus Sattler (rewrite the code for UART0 + UART1 support in ESP8266)
 Modified 25 April 2015 by Thomas Flayols (add configuration different from 8N1 in ESP8266)
 Modified 13 October 2018 by Jeroen Döll (add baudrate detection)
 Baudrate detection example usage (detection on Serial1):
   void setup() {
     Serial.begin(115200);
     delay(100);
     Serial.println();

     Serial1.begin(0, SERIAL_8N1, -1, -1, true, 11000UL);  // Passing 0 for baudrate to detect it, the last parameter is a timeout in ms

     unsigned long detectedBaudRate = Serial1.baudRate();
     if(detectedBaudRate) {
       Serial.printf("Detected baudrate is %lu\n", detectedBaudRate);
     } else {
       Serial.println("No baudrate detected, Serial1 will not work!");
     }
   }

 Pay attention: the baudrate returned by baudRate() may be rounded, eg 115200 returns 115201
 */

#ifndef HardwareSerial_h
#define HardwareSerial_h

#include <inttypes.h>
#include <functional>
#include "Stream.h"
#include "esp32-hal.h"
#include "soc/soc_caps.h"
#include "HWCDC.h"
#include "__USBCDC.h"

#include "freertos/FreeRTOS.h"
#include "freertos/task.h"
#include "freertos/semphr.h"

enum SerialConfig {
  SERIAL_5N1 = 0x8000010,
  SERIAL_6N1 = 0x8000014,
  SERIAL_7N1 = 0x8000018,
  SERIAL_8N1 = 0x800001c,
  SERIAL_5N2 = 0x8000030,
  SERIAL_6N2 = 0x8000034,
  SERIAL_7N2 = 0x8000038,
  SERIAL_8N2 = 0x800003c,
  SERIAL_5E1 = 0x8000012,
  SERIAL_6E1 = 0x8000016,
  SERIAL_7E1 = 0x800001a,
  SERIAL_8E1 = 0x800001e,
  SERIAL_5E2 = 0x8000032,
  SERIAL_6E2 = 0x8000036,
  SERIAL_7E2 = 0x800003a,
  SERIAL_8E2 = 0x800003e,
  SERIAL_5O1 = 0x8000013,
  SERIAL_6O1 = 0x8000017,
  SERIAL_7O1 = 0x800001b,
  SERIAL_8O1 = 0x800001f,
  SERIAL_5O2 = 0x8000033,
  SERIAL_6O2 = 0x8000037,
  SERIAL_7O2 = 0x800003b,
  SERIAL_8O2 = 0x800003f
};

typedef uart_mode_t SerialMode;
typedef uart_hw_flowcontrol_t SerialHwFlowCtrl;

typedef enum {
  UART_NO_ERROR,
  UART_BREAK_ERROR,
  UART_BUFFER_FULL_ERROR,
  UART_FIFO_OVF_ERROR,
  UART_FRAME_ERROR,
  UART_PARITY_ERROR
} hardwareSerial_error_t;

#ifndef ARDUINO_SERIAL_EVENT_TASK_STACK_SIZE
#ifndef CONFIG_ARDUINO_SERIAL_EVENT_TASK_STACK_SIZE
#define ARDUINO_SERIAL_EVENT_TASK_STACK_SIZE 2048
#else
#define ARDUINO_SERIAL_EVENT_TASK_STACK_SIZE CONFIG_ARDUINO_SERIAL_EVENT_TASK_STACK_SIZE
#endif
#endif

#ifndef ARDUINO_SERIAL_EVENT_TASK_PRIORITY
#ifndef CONFIG_ARDUINO_SERIAL_EVENT_TASK_PRIORITY
#define ARDUINO_SERIAL_EVENT_TASK_PRIORITY (configMAX_PRIORITIES - 1)
#else
#define ARDUINO_SERIAL_EVENT_TASK_PRIORITY CONFIG_ARDUINO_SERIAL_EVENT_TASK_PRIORITY
#endif
#endif

#ifndef ARDUINO_SERIAL_EVENT_TASK_RUNNING_CORE
#ifndef CONFIG_ARDUINO_SERIAL_EVENT_TASK_RUNNING_CORE
#define ARDUINO_SERIAL_EVENT_TASK_RUNNING_CORE -1
#else
#define ARDUINO_SERIAL_EVENT_TASK_RUNNING_CORE CONFIG_ARDUINO_SERIAL_EVENT_TASK_RUNNING_CORE
#endif
#endif

// UART0 pins are defined by default by the bootloader.
// The definitions for SOC_* should not be changed unless the bootloader pins
// have changed and you know what you are doing.

#ifndef SOC_RX0
#if CONFIG_IDF_TARGET_ESP32
#define SOC_RX0 (gpio_num_t)3
#elif CONFIG_IDF_TARGET_ESP32S2 || CONFIG_IDF_TARGET_ESP32S3
#define SOC_RX0 (gpio_num_t)44
#elif CONFIG_IDF_TARGET_ESP32C2
#define SOC_RX0 (gpio_num_t)19
#elif CONFIG_IDF_TARGET_ESP32C3
#define SOC_RX0 (gpio_num_t)20
#elif CONFIG_IDF_TARGET_ESP32C6
#define SOC_RX0 (gpio_num_t)17
#elif CONFIG_IDF_TARGET_ESP32H2
#define SOC_RX0 (gpio_num_t)23
#elif CONFIG_IDF_TARGET_ESP32P4
#define SOC_RX0 (gpio_num_t)38
#endif
#endif

#ifndef SOC_TX0
#if CONFIG_IDF_TARGET_ESP32
#define SOC_TX0 (gpio_num_t)1
#elif CONFIG_IDF_TARGET_ESP32S2 || CONFIG_IDF_TARGET_ESP32S3
#define SOC_TX0 (gpio_num_t)43
#elif CONFIG_IDF_TARGET_ESP32C2
#define SOC_TX0 (gpio_num_t)20
#elif CONFIG_IDF_TARGET_ESP32C3
#define SOC_TX0 (gpio_num_t)21
#elif CONFIG_IDF_TARGET_ESP32C6
#define SOC_TX0 (gpio_num_t)16
#elif CONFIG_IDF_TARGET_ESP32H2
#define SOC_TX0 (gpio_num_t)24
#elif CONFIG_IDF_TARGET_ESP32P4
#define SOC_TX0 (gpio_num_t)37
#endif
#endif

// Default pins for UART1 are arbitrary, and defined here for convenience.

#if SOC_UART_HP_NUM > 1
#ifndef RX1
#if CONFIG_IDF_TARGET_ESP32
#define RX1 (gpio_num_t)26
#elif CONFIG_IDF_TARGET_ESP32S2
#define RX1 (gpio_num_t)4
#elif CONFIG_IDF_TARGET_ESP32C2
#define RX1 (gpio_num_t)10
#elif CONFIG_IDF_TARGET_ESP32C3
#define RX1 (gpio_num_t)18
#elif CONFIG_IDF_TARGET_ESP32S3
#define RX1 (gpio_num_t)15
#elif CONFIG_IDF_TARGET_ESP32C6
#define RX1 (gpio_num_t)4
#elif CONFIG_IDF_TARGET_ESP32H2
#define RX1 (gpio_num_t)0
#elif CONFIG_IDF_TARGET_ESP32P4
#define RX1 (gpio_num_t)11
#endif
#endif
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

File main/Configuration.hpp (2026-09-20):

#pragma once
#include "esp_littlefs.h"
#include "esp_log.h"
#include "esp_netif_ip_addr.h"
//#include "lwip/ip4_addr.h"
#include "RotatorHW.h"
#include <string>
#include <mutex>

struct ConfigData {
    // Fourier coefficients
    double C0;
    std::array<double, KMAX+1> A;  // Index 0 will be ignored
    std::array<double, KMAX+1> B;

    // Network configuration
    std::string ipAddress;
    std::string netmask;
    std::array<uint8_t, 6> macAddress;

    // Which physical rotation direction counts as "positive" (increasing
    // Alpaca Position) by default, for this specific telescope/mount - see
    // RotatorHW::getDirection(). Application-specific (a property of how the
    // rotator is mounted on a given telescope), not device-specific, so it
    // lives here rather than in NVS alongside the angle-sensor calibration.
    bool nominalClockwise;

    // Where to ask for an independent output-shaft angle, for the
    // camera-referenced calibration. Empty means the feature is off, which
    // is the default and the only state a device without a camera is ever
    // in. A bare host or IP becomes http://<host>/angle; anything starting
    // with "http" is used verbatim, which is what lets the same button run
    // against a host-side service while RotatorCam does not serve angles
    // itself yet.
    std::string cameraAngleSource;

    // Full-step-resolution residual correction, layered on top of C0/A/B -
    // see RotatorHW::setFullStepTable()'s comment. All-zero (a no-op) until
    // a camera-referenced fit has been uploaded. Appended last (not grouped
    // with the Fourier coefficients above) so this struct's existing
    // positional aggregate-initializer in Configuration.cpp - {C0, A, B,
    // ipAddress, netmask, macAddress, nominalClockwise} - never has to shift
    // when adding a field; only ever append here.
    std::array<float, N_STEPS> fullStepTable{};
};

class Configuration {
public:
    // Access of the singleton
    static Configuration& getInstance();
    // mount the filesystem - called internally
    bool mountLittleFS();

    // Setter / Getter
    // Fourier-Koeffizienten
    double getC0() const;
    double getA(int k) const;
    double getB(int k) const;
    void  setC0(double v, bool s=true);
    void  setA(int k, double v, bool s=true);
    void  setB(int k, double v, bool s=true);

    // Netzwerk
    std::string getIPAddressString() const;
    uint32_t getIPAddressInt() const;
    std::string getNetmaskString() const;
    uint32_t getNetmaskInt() const;
    std::array<uint8_t,6> getMACAddress() const;
    void setIPAddress(const std::string& ip);
    void setNetmask(const std::string& nm);
    void setMACAddress(const std::array<uint8_t,6>& mac);

    // Nominal rotation direction - see ConfigData::nominalClockwise.
    bool getNominalClockwise() const;
    void setNominalClockwise(bool clockwise);

    // Independent angle source - see ConfigData::cameraAngleSource.
    std::string getCameraAngleSource() const;
    void setCameraAngleSource(const std::string &source);
    // The full URL to GET, derived from the setting above. Empty when the
    // feature is off.
    std::string getCameraAngleUrl() const;

    // Full-step correction table - see ConfigData::fullStepTable.
    void getFullStepTable(float outTable[N_STEPS]) const;
    void setFullStepTable(const float table[N_STEPS]);

    // Which calibration the stored correction is. Bumped whenever the
    // coefficients actually change, and stamped into the two artefacts
    // derived from them - the full-step table here and the mechanical-zero
    // target in RotatorHW - so that a correction replaced without
    // re-measuring those can be detected instead of silently misapplied.
    // See the comment on AngleCalBlob in Configuration.cpp.
    uint32_t calibrationGeneration() const { return _generation; }

    // True when the stored full-step table belonged to a different
    // calibration and was therefore dropped at load.
    bool fullStepTableStale() const { return _fullStepTableStale; }

private:
    Configuration();              // mountet FS und lädt JSON
    ~Configuration();

    // nicht kopierbar
    Configuration(const Configuration&)=delete;
    Configuration& operator=(const Configuration&)=delete;

    bool load();                  // loads /lfs/config.json
public:
    bool save() const;            // writes
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

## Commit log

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2026-08-28 feat: add hardware CAD sources, fix OTA GitHub redirect handling
    Add OpenSCAD design and exported STL/OBJ/3MF files for the rotator
    housing and mount hardware.
    Fix OTA manifest/asset fetch: GitHub release redirects can carry a
    900+ byte S3-signed Location header and terminate with
    Content-Length: 0, which overflowed the old 1024-byte location buffer
    and tripped esp_http_client's automatic chunked-body drain. Follow
    redirects and read response bodies by hand instead, with a larger
    location buffer and TX buffer sized for the long request line.
    [BigPulley.obj, BigPulley.scad, Bottom.3mf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]
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2026-08-29 feat: add Debug tab with rotator state and log window
    Port QlockThreeW32's Debug tab: a ring buffer of the last 200 log
    lines captured via esp_log_set_vprintf() (catches this project's own
    ESP_LOGx calls and the WiFi/USB driver's alike, so no RemoteDebug tee
    is needed the way the Arduino original required), served over
    GET /log?since=N alongside uptime/heap/reset-reason, gated behind the
    existing expert lock. The web UI polls it with sequence numbers so a
    freshly opened tab fills in one go and a restart is detected rather
    than silently mixing two boots together.
    [LogBuffer.c, main.cpp]
2026-08-29 fix: otaPoll stack overflow crashing the rotator ~2 minutes after boot
    Root cause: xTaskCreate(periodic_task, "otaPoll", 4096, ...) sized the
    task before OTA_LOCATION_BUF grew from 1024 to 2048 bytes to fit
    GitHub's longer redirect URLs. fetch_manifest() alone carries two
    buffers of that size on the stack (4 KB) before esp_http_client, the
    TLS handshake and cJSON add their own frames - comfortably overflowing
    a 4 KB task stack the first time periodic_task calls it, 120 seconds
    after boot on schedule. Reported as a bare "panic" reset with no
    useful text, since ESP-IDF's stack-overflow abort bypasses the normal
    logging path entirely. Sized otaPoll like otaInstall, which already
    runs the same r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
    [LogBuffer.c, RotatorHW.cpp]
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2026-08-29 feat: gate Update, Debug and Storage behind expert mode via #expert
    Ported QlockThreeW32's expert-mode entry point: Position, Network, WLAN
    and Calibration stay open, and Update/Debug/Storage - the tabs that can
    already flash firmware, browse the raw filesystem and read NVS - only
    appear in the tab row once expert mode is unlocked. There is no chip for
    it; #expert in the address is the way in, same as upstream, so nothing
    invites a visitor to go looking who has not already.
    New Expert.svelte carries the enroll/unlock/lock flow and the
    forgotten-password reset window, using this project's own separate
    /expert/* endpoints rather than QlockThreeW32's single-endpoint form -
    Rotator already had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
2026-09-06 fix: persist angle sensor calibration and correct its harmonic phase basis
    calibrateAngleSensor() previously called cfg.setA/setB/setC0 with
    save=false and never called cfg.save(), so a completed calibration was
    silently lost on the next restart. The Fourier fit also correlated
    harmonics against an angle accumulated from the step index instead of
    the actually measured sensor reading, which only matches how
    correctSensorReading() applies the correction when a run happens to
    start at raw sensor value 0 - any other starting position phase-rotates
    the fitted harmonics. A live run measured this as a ~50 degree spurious
    "before" residual.
    Also sweeps 2 full revolutions (averaging the wrapped per-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
    [RotatorHW.cpp, WebServer.cpp]
2026-09-07 feat: add a raw microstep jog debug endpoint for offline calibration work
    POST /api/debug/jog moves the motor by a signed, raw microstep count
    and returns a sensor/position snapshot, with a caller-chosen AS5600
    averaging depth. Lets an external script drive calibration/filter
    experiments (e.g. a from-scratch sensor+motor model feeding a Kalman
    filter) directly against the hardware without a firmware rebuild and
    reflash per iteration. Expert-gated like the rest of this file's raw
    hardware access, with a ~2-revolution distance clamp so a mistaken
    value can't block the HTTP server task or spin the motor unexpectedly
    far.
    Confirmed on the bench: a +50/-50 microstep round trip returns to the
    exa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
    [RotatorHW.cpp, WebServer.cpp]
2026-09-07 feat: add a Python calibration lab script for the debug jog endpoint
    Drives the rotator via POST /api/debug/jog (no numpy/pandas - stdlib
    only, so it runs anywhere Python 3 does) to let sensor/motor
    calibration models and fusion filter ideas be tried against the real
    hardware without a firmware rebuild+reflash cycle. Mirrors
    RotatorHW.cpp's Fourier fit and residual maths so results are directly
    comparable. Includes a noise-floor probe, a full-step sensor sweep, a
    fine microstep sweep for the motor's own within-step nonlinearity, and
    a directional-approach backlash check, plus a free position round-trip
    consistency check on every sweep.
    Confirmed live: a 2-revolution sensor sweep plus a 4x12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
    [calibration_lab.py]
2026-09-07 feat: add motor-scale, EKF fusion and fault-injection to calibration lab
    Extends scripts/calibration_lab.py with:
    - motor_scale_from_sensor_sweep(): the revolution-averaged counts/
    microstep scale from the sensor sweep's own data, as a global
    correction to the ideal step-angle assumption.
    - SensorMotorEKF: the simplest useful version of the EKF sketched (but
    left unfinished) in RotatorHW.cpp's h_meas()/H_jacobian()/
    ekf_predict()/ekf_update() - predicts through the measured motor
    scale, updates through the fitted AS5600 eccentricity model.
    - ekf-walk command: collects a random walk of moves with a heavily-
    averaged "truth" reading and a lightly-averaged "operational"
    reading at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
    [calibration_lab.py]
2026-09-07 feat: add a browser-based first-flash page via GitHub Pages
    Same esp-web-tools mechanism as DoorOpener and QlockThreeW32: a stable
    release now also builds an ESP Web Tools manifest straight from ESP-IDF's
    own flasher_args.json/littlefs-flash_args (so it can't drift from the
    actual partition layout), attaches the bootloader/partition-table/otadata
    images to the release, and deploys docs/ plus those images to GitHub
    Pages so a blank XIAO ESP32-S3 can be flashed from Chrome/Edge without
    the dev container.
2026-09-07 feat: add a full-step motor reference point, fix a handler-table overflow it exposed
    RotatorHW::alignToFullStep() drives the stepper to a true mechanical
    full-step position (via the same proven-safe forwardStep()+delay()
    primitive calibrateAngleSensor() already uses for this microstep-mode
    switch) and returns the resulting step position as a phase-0 reference
    for motor-wobble analysis over /api/debug/jog, exposed as
    POST /api/debug/align-fullstep.
    Adding that one extra route tipped the HTTP server's handler table over
    http_cfg.max_uri_handlers=64, which the Alpaca common+Rotator routes,
    WebServer's own routes, OTA, expert lock, file/NVS browsing and the log
    endpoint already filled almost ex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
    [RotatorHW.cpp, WebServer.cpp, calibration_lab.py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]
2026-09-07 fix: stop TMC2209 setRunCurrent() overriding the computed RMS current
    setRunCurrent(100) ran right after setRMSCurrent() and forced IRUN to
    CS=31 (~980mA at this Rsense/vsense), discarding the current-scale value
    setRMSCurrent() had just computed, while IHOLD stayed at the small
    setRMSCurrent()-derived value - a ~16:1 run:hold mismatch. At this
    motor's 5V supply the coil can physically draw at most ~290mA, so
    StealthChop's current regulator saturated its PWM duty cycle for most
    of each microstep's sine/cosine wave, only regulating correctly near
    the zero crossings - a likely major contributor to measured motor
    wobble. enableCoolStep() compounded this by pulling current below the
    run setting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
    [RotatorHW.cpp, calibration_lab.py]
2026-09-08 refactor: drop the dead EKF scaffold, start a fresh angle-filter lab
    Removes the unfinished, never-called EKF sketch in RotatorHW.cpp
    (h_meas()/H_jacobian()/ekf_predict()/ekf_update(), the commented-out
    test block in begin(), and the now-unused Q/R/x/P members and
    SCALE_S), and the SensorMotorEKF/cmd_ekf_walk/analyze_ekf_walk
    prototype that used to live in calibration_lab.py. Both were earlier,
    now-abandoned attempts at the same goal.
    Adds scripts/angle_filter_lab.py as a fresh, more narrowly-scoped
    start: a plain linear Kalman filter over the unwrapped OUTPUT-shaft
    angle (not the AS5600's own motor-shaft degree convention), with the
    static sensor-eccentricity correction applied once up fro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
    [RotatorHW.cpp, WebServer.cpp, calibration_lab.py]
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2026-09-10 feat: independent camera-based angle reference and eccentricity calibration
    Captures a full output-shaft revolution through RotatorCam and tracks the
    printed checkerboard's rotation via sub-pixel corner detection, giving this
    project its first ground truth that isn't derived from the AS5600 itself -
    the sensor sits on the motor shaft, upstream of the 10:1 reduction, and
    structurally cannot see the output stage or its own mounting error.
    camera_angle_sweep.py drives the sweep and photographs at each point
    (stdlib-only). camera_angle_analyze.py (needs numpy/opencv, see
    requirements-camera-analysis.txt) tracks rotation frame-to-frame via a
    Procrustes rotation fit and refits the AS5600's harmon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
2026-09-10 feat: closed-loop PI position control with Kalman-filtered AS5600 feedback
    Ports the live-validated Python prototype (scripts/pi_position_control.py)
    into RotatorHW::refineToTarget(), called from putRelativePosition(),
    putAbsolutePosition() and putMechanicalPosition() right after the existing
    open-loop MOVETO_WAIT. Measures via the AS5600 (Kalman-filtered, same
    predict/update as scripts/angle_filter_lab.py's AngleKalman1D) and issues
    small PI-controlled corrective jogs until within tolerance - conditional
    integration (only integrate while |error| < 0.05 deg) is required, a plain
    PI overshot badly without it in live testing before this port.
    100 independently camera-verified random moves (se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
    [RotatorHW.cpp, calibration_lab.py]
2026-09-10 fix: getPosition() AS5600 fine term misaligned with its own coarse bins
    getPosition() combined a stepPosition-derived coarse term ("which 36 degree/
    AS5600-revolution bin") with a fine term computed from a fresh AS5600
    reading referenced against _zeroPosSensorValue - a homing-time constant with
    no defined relationship to getMechanicalPosition()'s own bin boundaries
    (stepPosition == 0). The two terms could disagree by nearly a full AS5600
    revolution depending on where the last homing happened to land; live-
    measured against an independent camera reference (via the new closed-loop
    end-to-end test), the discrepancy was ~0.25-0.7 deg - large enough to matter
    for both the Alpaca Position readback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
    [RotatorHW.cpp]
2026-09-10 feat: add /api/debug/goto-mechanical-zero to trigger homing on demand
    RotatorHW::gotoMechanicalZero() previously only ran once, at boot
    (main.cpp) - measuring its repeatability required a reboot (WiFi
    reconnect, full startup sequence) per attempt. This exposes the exact
    same routine via an expert-gated debug endpoint, for
    scripts/homing_repeatability.py to call directly.
    Live-verified: 22.3s per call (matches the routine's own ~10s hardcoded
    settle delay plus the Hall sweep and microstep edge search), returns
    stepPosition=0 and a correctedSensor reading close to the calibrated
    _zeroPosSensorValue (26.556 vs 27).
    [WebServer.cpp]
2026-09-10 fix: rework boot-time homing as sector-confirm + jump to a calibrated NVS target
    The previous gotoMechanicalZero() matched a raw AS5600 value against the
    whole Hall-active window (~166 motor-shaft degrees, several AS5600 periods
    wide) using shortest-wrap distance, which could lock onto the wrong motor
    revolution - camera-verified at ~1-in-12 boots landing exactly N*36 output
    degrees off.
    Splits homing into a one-time calibration (unchanged measureMechanicalZero()/
    findEdge() binary search, now persisting its result via
    setZeroPosSensorValue() into NVS namespace "homing") and a fast boot-time
    step that only needs to confirm which sector it's in: a debounced Hall sweep
    (sweepUntilHallChange()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
    [RotatorHW.cpp, WebServer.cpp]
2026-09-10 feat: move angle-correction Fourier coefficients from config.json into NVS
    All calibration values now live in NVS, matching the mechanical-zero target
    persisted there earlier: a new "anglecal"/"coeffs" blob holds C0/A[]/B[],
    loaded in preference to config.json and migrated from it once for existing
    devices. config.json keeps only the USB RNDIS network settings.
    Live-verified: correctedSensor at boot-time mechanical zero was 21.556
    before the flash and 22.556 after (same order as run-to-run noise already
    seen in this session), stepPosition=0 and hall=true in both cases.
    [Configuration.hpp]
2026-09-10 fix: stop retrying SSE progress sends into a dead calibration-stream client
    calibration_zero_stream() and calibration_angle_stream()'s send_event()
    helper ignored httpd_resp_send_chunk()'s return value. Once a client
    disconnects mid-stream, every subsequent send into the dead socket blocks
    for a real send timeout (~600ms, live-measured) before failing - for a
    ~800-step full-step calibration sweep, that turns a lost browser tab or
    curl timeout into many minutes of the httpd worker retrying sends nobody
    reads, indistinguishable from a hang. Fixed by checking the return value
    and suppressing further send attempts once the client is confirmed gone,
    without aborting the underlying measurement - i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
    [WebServer.cpp]
2026-09-11 fix: bring the Rotator Alpaca API in line with the ASCOM spec
    Audited every Rotator-specific and common endpoint against the ASCOM
    Alpaca API reference (ascom-standards.org) and its official reference
    implementation (ASCOMInitiative/AlpycaDevice). Found and fixed:
    - No property or method checked Connected first. Per spec, every Rotator
    member except CanReverse (a static capability) must return
    NotConnectedException (0x407) when the client hasn't connected -
    previously they all just executed regardless. Added
    rotator_require_connected(), applied to ismoving, mechanicalposition,
    position, reverse (get+put), stepsize, targetposition, halt, move,
    moveabsolute, movemechanical and syn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
    [RotatorHW.cpp]
2026-09-11 feat: implement Rotator.Reverse, report StepSize as sensor resolution
    Reverse was previously a no-op: _isReverse was stored but never consulted
    by any position/motion code. Per the Alpaca spec (rotator.html's note on
    Rotator.Reverse): rotation is normally counterclockwise-from-behind,
    matching increasing equatorial Position Angle; Reverse=true means
    increasing Position now corresponds to clockwise rotation instead. That
    is a sign flip in the mechanical<->Position mapping - independent of the
    Sync() offset, and distinct from MechanicalPosition, which must stay a
    raw, unaffected readout (both already true here, confirmed unchanged).
    getPosition(), putRelativePosition(), putAbsolutePosition(),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
    [RotatorHW.cpp]
2026-09-11 feat: add cable-wrap motion limit (+/-190 deg from mechanical zero)
    Once a camera is attached via a cable, the rotator must never travel
    further than a fixed limit from mechanical zero (raw step 0, set by the
    last successful gotoMechanicalZero()) - Franz's number, sized for the
    planned cable.
    Move/MoveAbsolute/MoveMechanical now resolve their target through
    legalMotorStepsForAngle(): for the desired wrapped mechanical angle, try
    the shortest-path candidate first, then the same physical orientation
    reached one full turn further (candidate -/+ 360 deg) if the shortest one
    would exceed the limit. Since MOTION_LIMIT_DEG (190) is just over half of
    360, at least one candidate is always within it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
    [RotatorHW.cpp]
2026-09-11 feat: continuous position holding, configurable nominal direction, manual goto
    Rotator now has two motion states, per Franz's request: a commanded move
    (put*Position()/gotoMechanicalZero()) drives the motor to a target as
    before, and once it settles, a new background task takes over to hold that
    target against drift (cable tension, an unbalanced camera) - the same
    Kalman-filtered PI control law as refineToTarget(), just run continuously
    at a fixed 150ms cadence instead of stopping after convergence. A real
    actuation threshold (0.01 deg, refineToTarget()'s own tolerance) gates
    whether a cycle actually moves the motor - the PI state itself (integral,
    Kalman estimate) still updates every cycle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
    [Configuration.hpp, RotatorHW.cpp, WebServer.cpp]
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2026-09-11 build: stamp ROTATOR_VERSION on every build, not just once at configure time
    The previous mechanism computed the version via `git describe` once, in
    the top-level CMakeLists.txt's execute_process() at CMake configure time,
    then baked it in via add_compile_definitions(). CMake only reruns that
    block when it reconfigures, which a plain `idf.py build` after committing
    or tagging does not trigger - the reported version (footer, /ota/status,
    Alpaca driverversion) then quietly goes stale until something forces a
    reconfigure. Exactly what happened after tagging v0.9.1: the device kept
    reporting "0.9.0-dirty" until a full rebuild.
    Ported the fix from QlockThreeW32's scripts/version.py (PlatformIO/S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
2026-09-11 feat: full-step-resolution AS5600 correction table, layered on the Fourier model
    The existing C0/A[]/B[] Fourier model (order<=KMAX=4) is a smooth,
    low-frequency fit and structurally cannot represent error that repeats
    once per full motor step rather than once per revolution. Live-measured
    (scripts/calibration_lab.py's fullstep-accuracy command, 2026-09-11): an
    order-6 self-referential fit still left RMS=1.30 deg/peak=3.56 deg
    (motor-shaft) at full-step resolution, yet that residual correlates
    +1.000 between two independently measured revolutions (diff RMS only
    0.049 deg) - a large but almost perfectly repeatable, and therefore
    almost perfectly correctable, error no smooth harmonic fit can r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
    [Configuration.hpp, RotatorHW.cpp, WebServer.cpp]
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2026-09-19 fix: read the AS5600's RAW ANGLE register, not ANGLE
    The AS5600 applies a documented ~10 LSB hysteresis to its ANGLE register at
    the limit of the 360 degree range, to keep the output from toggling there.
    On this rotator that put a dead band across the sensor's wrap: measured with
    a one-count fine sweep, travelling upwards the output stuck at exactly 4095
    for 275 microsteps - eleven counts of real motion reported as none - and
    then jumped straight to 11, while the same crossing downwards was smooth.
    That is 0.105 output degrees per motor revolution carrying no position
    information, ten times the accuracy this machine is aimed at, and it is a
    discontinuity no smooth correction model can repre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
    [RotatorHW.cpp]
2026-09-19 feat: reach every target from the same side, against gear backlash
    Backlash sits downstream of the AS5600, which is on the motor shaft, so the
    closed loop cannot see it: the sensor reaches the commanded angle either way
    while the output shaft rests on whichever side of the slack the last motion
    left it on. Measured against an output-shaft camera over 200 random Alpaca
    targets, that split the output by 64 mdeg peak to peak - larger than every
    other correctable error on this machine put together.
    refineToTarget() now finishes every approach moving in the positive
    direction: it backs off to BACKLASH_APPROACH_DEG below the target first
    whenever it would otherwise correct downwards, and treats a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
    [RotatorHW.cpp]
2026-09-19 feat: add the camera-referenced calibration campaign under scripts/calib
    A from-scratch calibration of the angle chain, driven from the host over the
    expert-gated debug endpoints and the Alpaca API, with the output-shaft
    chessboard camera as an independent reference. RESULTS.md has the measured
    numbers and the graphs; README.md has the pipeline and the three traps that
    cost the most time.
    What it established, on the one unit:
    - the sensor characteristic is 0.225 deg peak-to-peak and fits to 3.0 mdeg
    with a Fourier series of order 5. Orders 6 and up are 0.02-0.03 counts,
    i.e. noise, so the intended order 7 buys nothing;
    - the firmware's closed loop already holds the motor shaft to 4.5 m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
    [board.py, camera_model.py, capture_frames.py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]
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2026-09-20 feat: let the device run the output-angle calibration itself, against an external angle source
    A button and a field for the address to ask. The rotator knows how to move,
    fit and store; it does no image processing at all and just GETs a number.
    That split is the whole design decision, and it was estimated rather than
    assumed. Memory and flash would have been fine for doing the vision here -
    tjpgd is in the ESP32-S3 ROM, 600 KB of app partition is free, a 1600x1200
    grayscale frame is 1.9 MB against 8.26 MB of contiguous PSRAM. The
    chessboard detector is what does not fit: it would be the largest and least
    testable code in the project, and it would first pull a 270 KB JPEG over
    WiFi to reach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
    [Configuration.hpp, RotatorHW.cpp, WebServer.cpp]
2026-09-20 fix: run calibrations off the HTTP server's task
    ESP-IDF's httpd serves every socket from a single task, so an SSE handler
    that streams progress for minutes does not just occupy its own connection -
    the whole server stops answering. Every route: the status endpoint that
    would say what is going on, the Alpaca routes a client might be mid-session
    on, the log. All three calibrations did this; the output-angle one does it
    for over half an hour, and on 2026-09-19 one pointed at an unreachable angle
    source took the device off the network for hours.
    Moving only the measurement into a worker would not have helped, because the
    SSE handler is what holds the server task. So the request itself is hande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
    [WebServer.cpp, main.cpp]
2026-09-20 fix: stop the filesystem upload stalling its own socket, and give uploads longer
    The upload handler erased all 10 MB of the littlefs partition in one call
    before reading the rest of the body. That erase takes about twenty-four
    seconds, and for the whole of it the socket goes unread while the sender
    keeps pushing. Live on 2026-09-20 two uploads in a row died that way, each
    time leaving the partition erased and the device serving no web UI at all -
    strictly worse than a refused upload, and awkward to recover from if the
    browser is the only way in.
    Raising httpd's receive timeout from five seconds to twenty was the obvious
    guess and did not fix it, so the erase is now done lazily instead: one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
    [main.cpp]
